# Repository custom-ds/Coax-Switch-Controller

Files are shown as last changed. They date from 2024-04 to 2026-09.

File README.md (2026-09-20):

# Coax Switch Controller

A WiFi-enabled coax antenna switch controller for amateur radio stations. It allows two radios to select one of six antennas each, with relay control driven by a custom PCB and an ESP32-based controller. The system supports both a front-panel interface and a built-in web UI / REST API.

## Overview

This project is designed to let a station operator:

- switch each radio between up to six antenna outputs
- optionally disconnect a radio from all antennas
- control the switch from the local front panel using a rotary knob and LCD
- control the switch from a browser or automation client over WiFi
- retain configuration and last-known antenna selections across reboots

The repository is divided into three main parts:

- [Firmware/](Firmware/) — ESP32 firmware for control logic, WiFi, API routes, and UI generation
- [Coax Switch Controller/](Coax%20Switch%20Controller/) — KiCad PCB design and fabrication outputs
- [3d Case/](3d%20Case/) — enclosure body, lid, and printable STL/BGCode exports

## Features

- Dual-radio antenna switching with six antenna positions per radio
- Shared collision protection so both radios cannot be assigned the same antenna simultaneously
- Persistent antenna state stored in ESP32 flash using Preferences
- Front-panel rotary knob and 16x2 LCD interface
- Built-in web interface served by the ESP32 itself
- REST-style API for external control and automation
- WiFi configuration with optional static IP support
- Custom relay-driver PCB design included in the repo

## Hardware

The firmware targets the SparkFun ESP32 Thing Plus C board. The controller also uses:

- SparkFun 16x2 SerLCD display
- SparkFun Qwiic Twist rotary knob
- custom relay driver PCB for switching the antenna control lines
- external 12V supply for the relay bank

The antenna switching model is based on two independent 3-bit select paths, one for each radio, with a shared latch/enable signal to prevent unstable switching during changes.

## Repository Layout

```text
.
├── Firmware/
│   ├── Firmware.ino
│   ├── config.h.template
│   ├── config.h
│   ├── README.md
│   └── LICENSE
├── Coax Switch Controller/
│   ├── Coax Switch Controller.kicad_pro
│   ├── Coax Switch Controller.kicad_sch
│   ├── Coax Switch Controller.kicad_pcb
│   ├── Bill of Materials.csv
│   └── Gerber/
├── 3d Case/
│   ├── Enclosure.FCStd
│   ├── Lid.FCStd
│   ├── .stl exports
│   └── related print files
├── README.md
├── test_config.html
├── test_interface.html
├── LICENSE
└── CLAUDE.md
```

## Firmware Build and Upload

The firmware is developed primarily in the Arduino IDE, although it can be edited in VS Code and uploaded from the Arduino IDE while both are pointed at the same .ino file.

### Required software

Install the following in the Arduino IDE:

1. ESP32 board package by Espressif Systems
2. Required libraries:
   - AsyncTCP
   - ESPAsyncTCP
   - ESPAsyncWebSrv
   - SparkFun Qwiic Twist Arduino Library
   - SparkFun SerLCD Arduino Library

### Important build flag for regex routes

The ESPAsyncWebSrv routes use regex matching for the API handlers. Without this flag, the web routes may silently fail to match.

For Arduino IDE, create or update the file:

- Windows: `%LOCALAPPDATA%\Arduino15\packages\espxxxx\hardware\espxxxx\{version}\platform.local.txt`
- Linux: `~/.arduino15/packages/espxxxx/hardware/espxxxx/{version}/platform.local.txt`

Add this line:

```text
compiler.cpp.extra_flags=-DASYNCWEBSERVER_REGEX=1
```

Then restart the Arduino IDE.

### Board selection and upload

1. Connect the ESP32 board over USB.
2. In Arduino IDE, choose the correct COM port.
3. Select the board: `SparkFun ESP32 Thing Plus C`.
4. Compile and upload the firmware.

> If the relay bank is already installed, the board may also require an external 12V input for the relay supply.

## Configuration

The firmware expects a local config file named `config.h` in [Firmware/](Firmware/). This file is intentionally gitignored and must be created from the template at [Firmware/config.h.template](Firmware/config.h.template).

The config file contains values for:

- WiFi SSID and password
- optional static IP configuration
- gateway, subnet, and DNS settings

Never commit the generated `config.h` file to version control.

## Web UI and API

The ESP32 serves a built-in web interface and REST-like endpoints for control and configuration. The firmware generates the HTML/CSS/JS dynamically rather than using a separate frontend project.

The repository also includes standalone browser preview files at the root:

- [test_interface.html](test_interface.html)
- [test_config.html](test_config.html)

These are useful for iterating on the interface layout without needing to flash the device each time.

## Front Panel Operation

The controller supports a front-panel workflow built around the rotary knob and LCD:

- normal mode allows selecting the active radio and changing the antenna
- the LCD shows current status and configuration information
- a long press enters configuration mode
- knob turns cycle through configuration screens
- a button click exits configuration mode and returns to the main operating view

## State Persistence

The controller stores persistent settings in the ESP32 `Preferences` namespace, including:

- last selected antenna per radio
- antenna names displayed in the UI
- LCD brightness and contrast settings
- knob RGB settings
- a long-lived API key

This ensures the device remembers its last configured state between power cycles.

## Project Notes

- There is no package manager or automated CI/test suite in this repo.
- Firmware development is hardware-focused and is flashed via the Arduino IDE.
- PCB and enclosure work is done in KiCad and FreeCAD, respectively.
- If the PCB or enclosure changes significantly, regenerate the output files manually so the exported fabrication artifacts remain consistent.

## More Information

For the most detailed firmware guidance, including required libraries, upload procedure, and environment setup, see [Firmware/README.md](Firmware/README.md).

For the PCB and enclosure sources, see:

- [Coax Switch Controller/](Coax%20Switch%20Controller/)
- [3d Case/](3d%20Case/)

## License

This project is distributed under the terms of the license included in [LICENSE](LICENSE).

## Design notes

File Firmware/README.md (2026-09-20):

# Coax Switch Controller - Firmware
The C firmware for the Sparkfun ESP32-based coax switch relay controller for amateur radio stations.

## Hardware
The W0ZC Coax Controller utilizes the "Sparkfun ESP32 Thing Plus C" as the main processor board and Wifi interface
for the coax switch controller. In addition, the Sparkfun 16x2 SerLCD module (Qwiic) and the Sparkfun Qwiic Twist
knob for interfacing.

A custom PCB is used to provide high side switching to the two sets of 6 coax relays.

## Programming the ESP32 

### Setting up the Environment
The ESP32 controller used in this project is the Sparkfun ESP32 Thing Plus C. To program it from the Arduino IDE 2.x 
platform, start by installing the board support tools.

In the Boards Manager section of Arduino IDE, search for the esp32 by Espressif Systems boards, and click the Install 
button.

**Important: install a 2.0.x release (2.0.17 is a good choice) of the esp32 board package, not 3.x.** The AsyncTCP/
ESPAsyncWebSrv libraries below are older forks that don't implement the lwIP TCPIP-core locking that Espressif's 3.x
board package (based on ESP-IDF v5.x) requires. Flashing this firmware with a 3.x board package installed will cause
the board to reboot in a loop with a crash like:

```
assert failed: tcp_alloc /IDF/components/lwip/lwip/src/core/tcp.c:1854 (Required to lock TCPIP core functionality!)
```

If you hit that, open Tools > Board > Boards Manager, install a 2.0.x version of "esp32 by Espressif Systems", select
it, restart the IDE, and re-upload.

There are some libraries that are required. Go to Tools and Manage Libraries. In the Search box, find and install these
libraries:

 * AsyncTCP (by dvarrel). Currently 1.1.4
 * ESPAsyncTCP (by dvarrel). Currently v1.2.4
 * ESPAsyncWebSrv (by dvarrel). Currently v1.2.7
 * Sparkfun Qwiic Twist Arduino Library (by Sparkfun Electronics). Currently v1.0.4
 * Sparkfun SerLCD Arduino Library (by Sparkfun Electronics). Currently v1.0.9

The ESPAsyncWebSrv utilizes Regular Expressions to handle some of the routing. This requires an additional file be
added to the Arduino IDE environment.

For arduino IDE: create/update platform.local.txt
 * Windows: C:\Users\(username)\AppData\Local\Arduino15\packages\espxxxx\hardware\espxxxx\{version}\platform.local.txt
 * Linux: ~/.arduino15/packages/espxxxx/hardware/espxxxx/{version}/platform.local.txt

Unless there are other items that have previously been added, the platform.local.txt file should just contain
a single line:

```
compiler.cpp.extra_flags=-DASYNCWEBSERVER_REGEX=1
```

### Programming the Firmware
Plug in the USB-C cable from the PC to the Sparkfun controller board. If the coax relays are already attached to the
Switch Controller, you may need to apply external 12V to the Controller.

Click the Select Board dropdown, and select the COM port that is associated with the Sparkfun device.

That will bring up another window where you can select the type of board being programmed. Scroll down or search the list
for "Sparkfun ESP32 Thing Plus C" and click the OK button.

In the upper left corner on the IDE, click the Right-Arrow (Upload) button to begin the compile and upload of the firmware.

### Using Visual Studio Code
I find it more efficient to code within Microsoft's Visual Studio Code, rather than directly in the Arduino IDE. To do that,
open up the .ino file inside of VSCode and make any code changes in there.

Leave the Arduino IDE open in the background, with the same .ino firmware file open. 

Modify the code inside of VSCode and save the changes. Alt-Tab into the Arduino IDE and just click the Upload button to 
load the firmware on the ESP32. If you need to make a small tweak inside of the Arduino IDE, go ahead and save, and VSCode
will immediately reflect the changes when to switch task back to it.

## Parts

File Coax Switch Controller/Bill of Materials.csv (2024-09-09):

Reference | Value | Datasheet | Footprint | Qty | DNP | DigiKey-PN | SparkFun-PN
C1,C3,C6 | 10uF | ~ | Capacitor_SMD:CP_Elec_4x5.3 | 3 |  | PCE3795CT-ND
C2,C4,C5,C7,C8,C9 | .01uF | ~ | Capacitor_SMD:C_0805_2012Metric_Pad1.18x1.45mm_HandSolder | 6 |  | C0603C103J5REC7411
D1,D2,D3,D4,D5,D6,D7,D8,D9,D10,D11,D12,D25 | 1N4007 | -- mixed values -- | Diode_SMD:D_SOD-123F | 13 |  | 1655-1N4007FLCT-ND
D13,D14,D15,D16,D17,D18,D19,D20,D21,D22,D23,D24 | LED | ~ | Diode_SMD:D_0805_2012Metric_Pad1.15x1.40mm_HandSolder | 12 |  | 732-4985-1-ND
FB1,FB2,FB3,FB4,FB5,FB6,FB7,FB8,FB9,FB10,FB11,FB12,FB13,FB14,FB15,FB16 | FerriteBead | ~ | Inductor_SMD:L_0805_2012Metric_Pad1.05x1.20mm_HandSolder | 16 |  | 240-2411-1-ND
H1,H2,H3,H4 | MountingHole | ~ | MountingHole:MountingHole_3.2mm_M3 | 4
J1,J2 | 8P8C | ~ | Connector_RJ:RJ45_Amphenol_54602-x08_Horizontal | 2 |  | 609-1046-ND
J3 | Screw_Terminal_01x02 | ~ | TerminalBlock_RND:TerminalBlock_RND_205-00001_1x02_P5.00mm_Horizontal | 1 |  | 732-10955-ND
Q1,Q2,Q3,Q4,Q5,Q6,Q7,Q8,Q9,Q10,Q11,Q12 | MMBT3904 | https://www.onsemi.com/pdf/datasheet/pzt3904-d.pdf | Package_TO_SOT_SMD:SOT-23 | 12 |  | MMBT3904TPMSCT-ND
Q13,Q14,Q15,Q16,Q17,Q18,Q19,Q20,Q21,Q22,Q23,Q24 | DMP2004K-7 |  | Package_TO_SOT_SMD:SOT-23 | 12 |  | DMP2004KDICT-ND
R1,R2,R3,R4,R5,R6,R7,R8,R9,R10,R11,R12 | 4.7k | ~ | Resistor_SMD:R_0805_2012Metric_Pad1.20x1.40mm_HandSolder | 12 |  | 311-4.70KCRCT-ND
R13,R14,R15,R16,R17,R18,R19,R20,R21,R22,R23,R24 | 100k | ~ | Resistor_SMD:R_0805_2012Metric_Pad1.20x1.40mm_HandSolder | 12 |  | 311-100KARCT-ND
R25,R26,R27,R28,R29,R30,R31,R32,R33,R34,R35,R36 | 10k | ~ | Resistor_SMD:R_0805_2012Metric_Pad1.20x1.40mm_HandSolder | 12 |  | 311-10.0KCRCT-ND
R37,R38,R39,R40,R41,R42,R43,R44,R45,R46,R47,R48 | 1k | ~ | Resistor_SMD:R_0805_2012Metric_Pad1.20x1.40mm_HandSolder | 12 |  | 311-1.00KCRCT-ND
U1 | ~ |  | Custom DS:ESP32-WROOM Thing Plus C | 1 |  |  | SPX-18018
U2,U3 | 74HC238 | http://www.ti.com/lit/ds/symlink/cd74hc238.pdf | Package_SO:SOIC-16_3.9x9.9mm_P1.27mm | 2 |  | 296-9188-5-ND
U4 | LM1085-5.0 | http://www.ti.com/lit/ds/symlink/lm1085.pdf | Package_TO_SOT_SMD:TO-263-3_TabPin2 | 1 |  | LM1086ISX-5.0/NOPBCT-ND

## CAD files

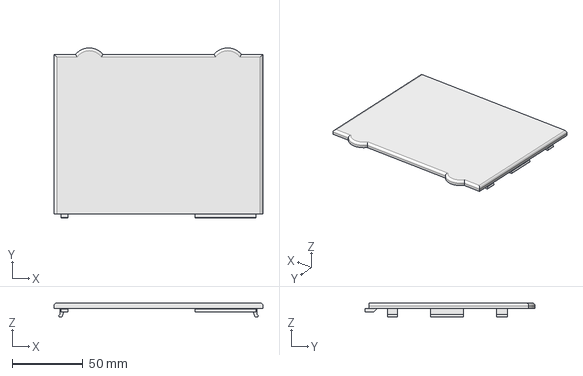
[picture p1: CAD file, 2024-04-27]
3d Case/Lid.FCStd
148.0 x 120.5 x 10.0 mm

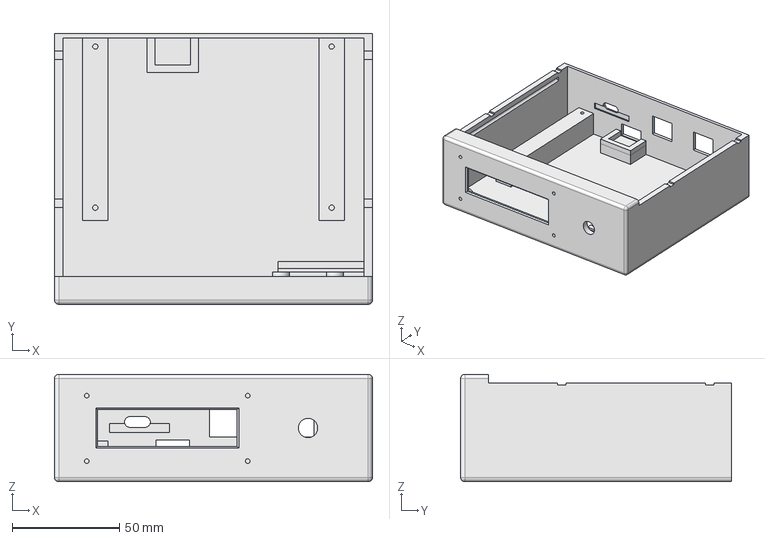
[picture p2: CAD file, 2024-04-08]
3d Case/Enclosure.FCStd
148.0 x 126.0 x 50.0 mm

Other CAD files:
3d Case/Enclosure-Body.stl
3d Case/Lid.stl

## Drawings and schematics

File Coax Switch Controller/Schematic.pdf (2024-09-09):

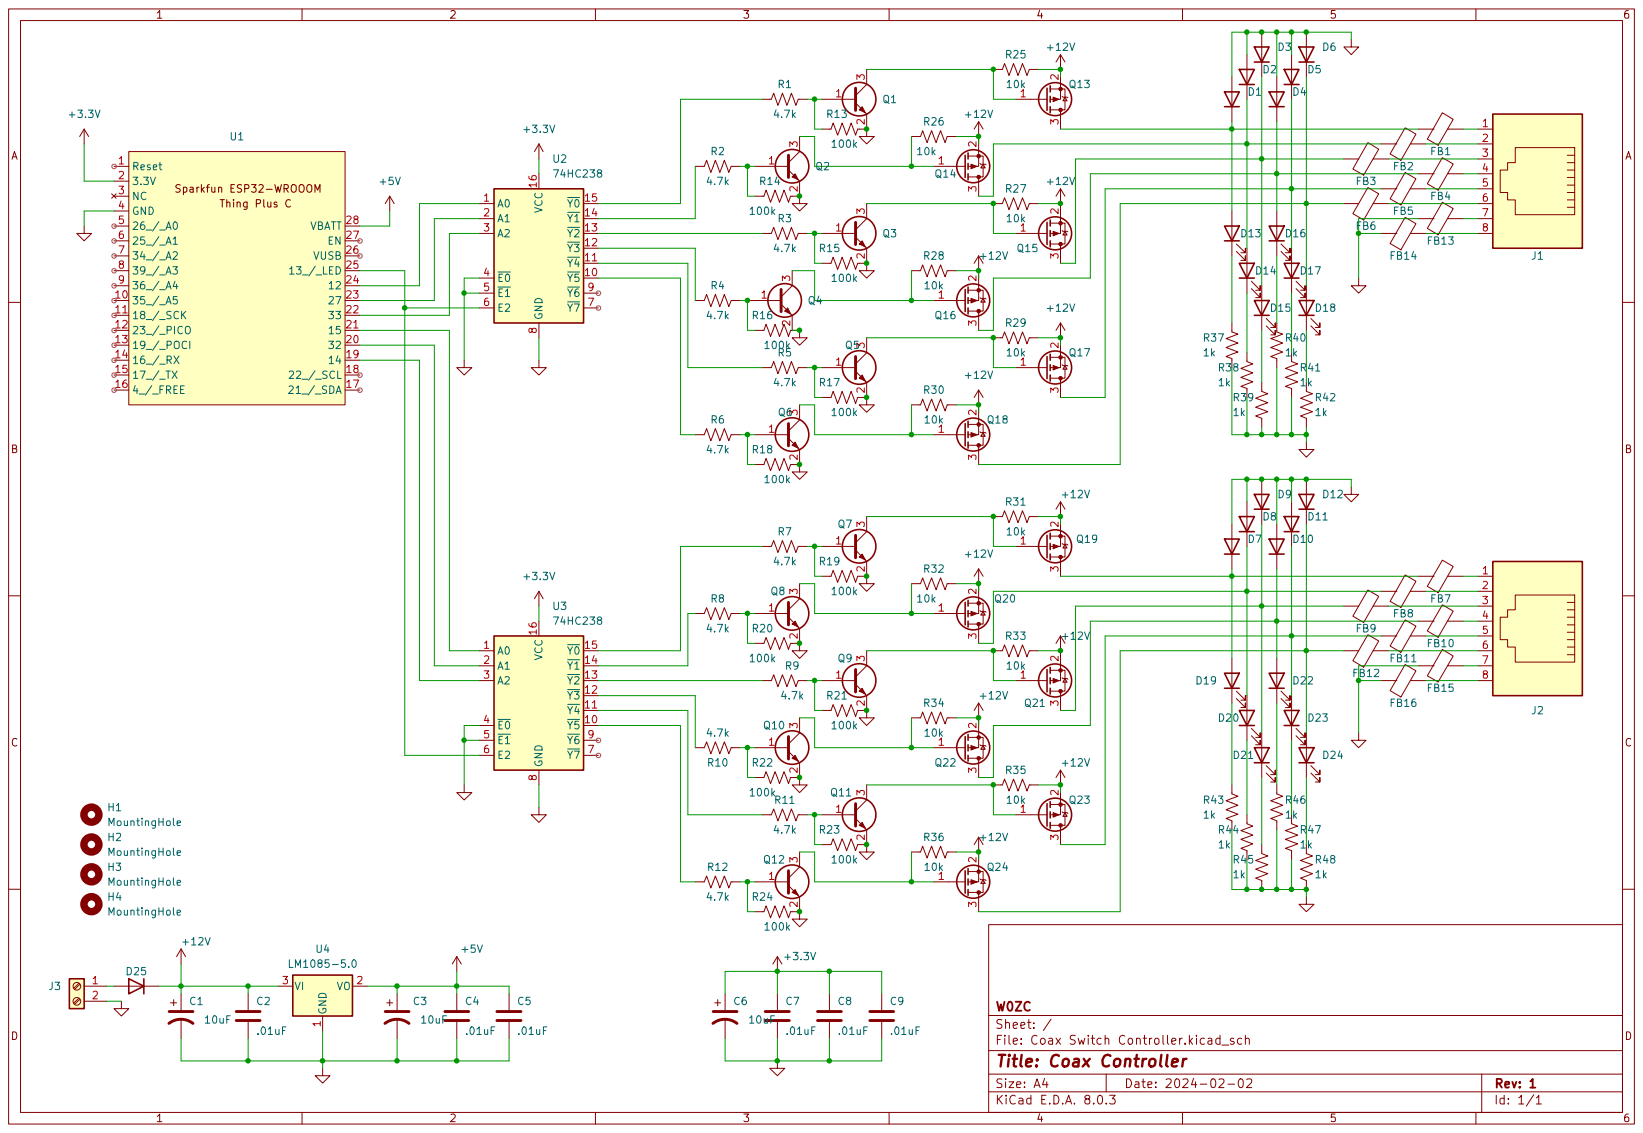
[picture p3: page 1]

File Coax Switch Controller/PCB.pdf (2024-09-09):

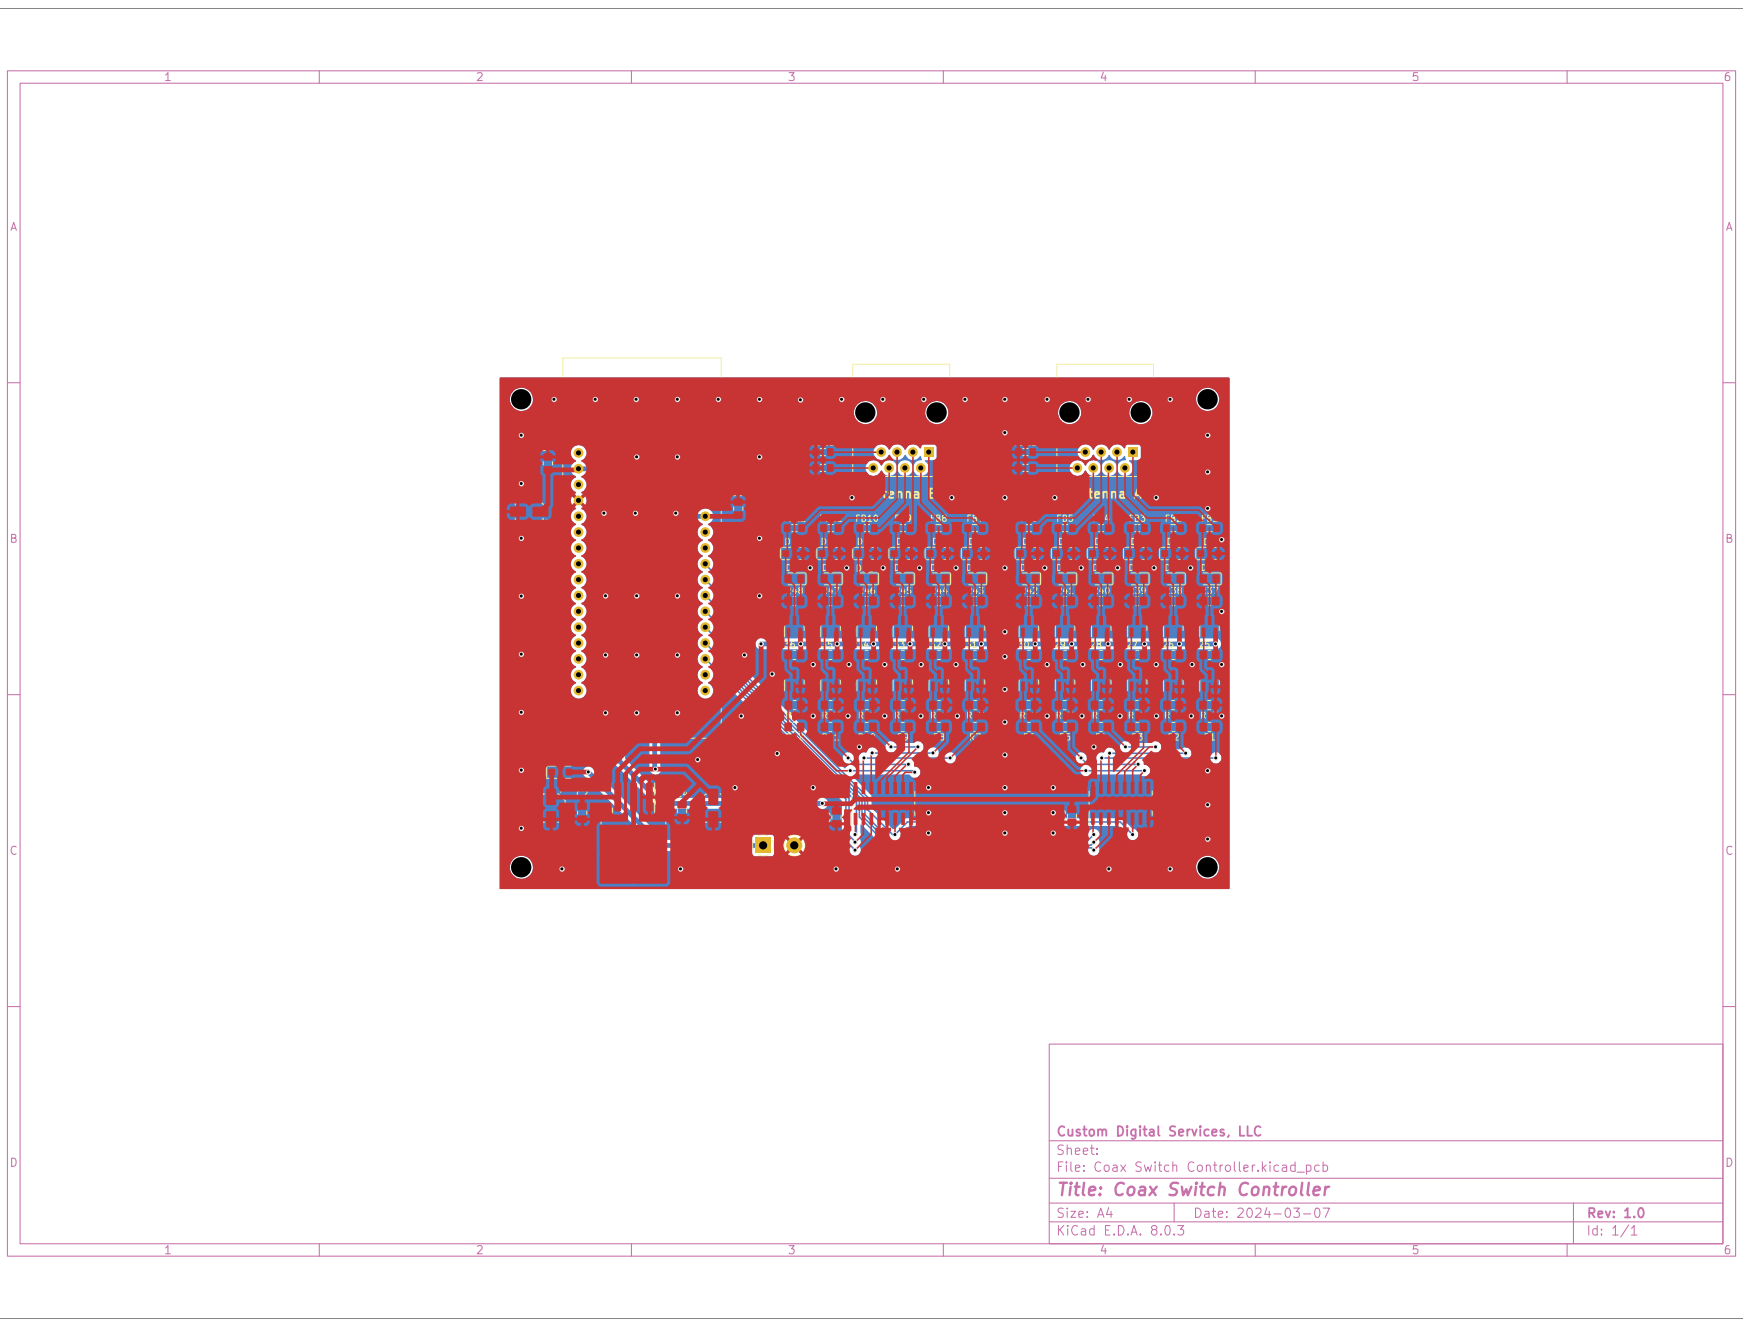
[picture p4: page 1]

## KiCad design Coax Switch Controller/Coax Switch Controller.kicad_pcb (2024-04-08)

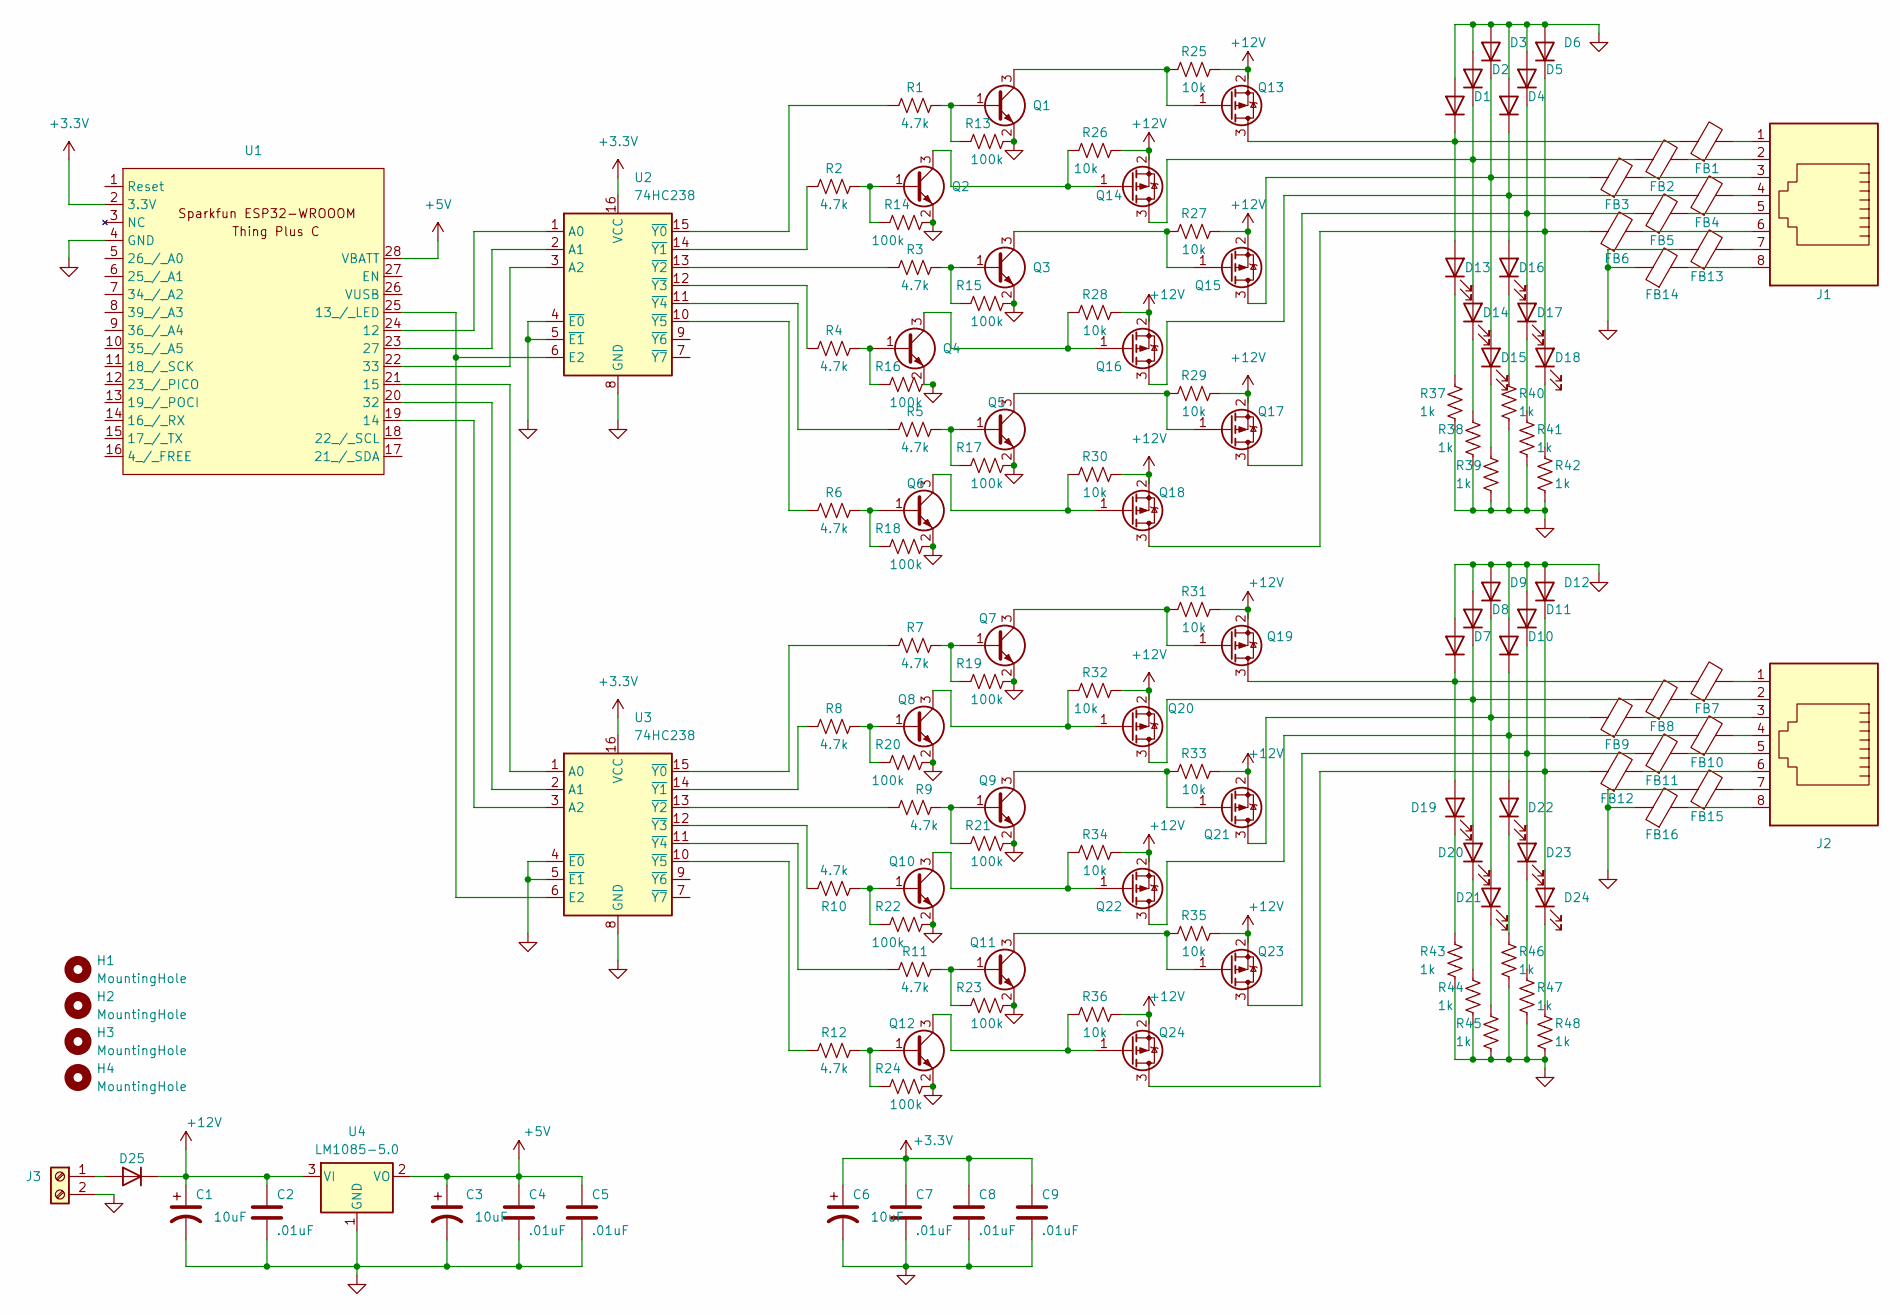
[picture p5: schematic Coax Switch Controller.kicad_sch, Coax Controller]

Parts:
C1, C3, C6: 10uF; CP_Elec_4x5.3
C2, C4, C5, C7, C8, C9: .01uF; C_0805_2012Metric_Pad1.18x1.45mm_HandSolder
D1, D2, D3, D4, D5, D6, D7, D8, D9, D10, D11, D12: MRA4007T3G; D_SOD-123F
D13, D14, D15, D16, D17, D18, D19, D20, D21, D22, D23, D24: LED; D_0805_2012Metric_Pad1.15x1.40mm_HandSolder
D25: 1N4007; D_SOD-123F
FB1, FB2, FB3, FB4, FB5, FB6, FB7, FB8, FB9, FB10, FB11, FB12, FB13, FB14, FB15, FB16: FerriteBead; L_0805_2012Metric_Pad1.05x1.20mm_HandSolder
H1, H2, H3, H4: MountingHole; MountingHole_3.2mm_M3
J1, J2: 8P8C; RJ45_Amphenol_54602-x08_Horizontal
J3: Screw_Terminal_01x02; TerminalBlock_RND_205-00001_1x02_P5.00mm_Horizontal
Q1, Q2, Q3, Q4, Q5, Q6, Q7, Q8, Q9, Q10, Q11, Q12: MMBT3904; SOT-23
Q13, Q14, Q15, Q16, Q17, Q18, Q19, Q20, Q21, Q22, Q23, Q24: DMP2004K-7; SOT-23
R1, R2, R3, R4, R5, R6, R7, R8, R9, R10, R11, R12: 4.7k; R_0805_2012Metric_Pad1.20x1.40mm_HandSolder
R13, R14, R15, R16, R17, R18, R19, R20, R21, R22, R23, R24: 100k; R_0805_2012Metric_Pad1.20x1.40mm_HandSolder
R25, R26, R27, R28, R29, R30, R31, R32, R33, R34, R35, R36: 10k; R_0805_2012Metric_Pad1.20x1.40mm_HandSolder
R37, R38, R39, R40, R41, R42, R43, R44, R45, R46, R47, R48: 1k; R_0805_2012Metric_Pad1.20x1.40mm_HandSolder
U1: ESP32-WROOM Thing Plus C
U2, U3: 74HC238; SOIC-16_3.9x9.9mm_P1.27mm
U4: LM1085-5.0; TO-263-3_TabPin2

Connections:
+3.3V: C6.1, C7.1, C8.1, C9.1, U1.2 (3.3V), U2.16 (VCC), U3.16 (VCC)
+5V: C3.1, C4.1, C5.1, U1.28 (VBATT), U4.2 (VO)
+12V: C1.1, C2.1, D25.1 (K), Q13.2 (S), Q14.2 (S), Q15.2 (S), Q16.2 (S), Q17.2 (S), Q18.2 (S), Q19.2 (S), Q20.2 (S), Q21.2 (S), Q22.2 (S), Q23.2 (S), Q24.2 (S), R25.2, R26.2, R27.2, R28.2, R29.2, R30.2, R31.2, R32.2, R33.2, R34.2, R35.2, R36.2, U4.3 (VI)
GND: C1.2, C2.2, C3.2, C4.2, C5.2, C6.2, C7.2, C8.2, C9.2, D1.2 (A), D2.2 (A), D3.2 (A), D4.2 (A), D5.2 (A), D6.2 (A), D7.2 (A), D8.2 (A), D9.2 (A), D10.2 (A), D11.2 (A), D12.2 (A), FB13.1, FB14.1, FB15.1, FB16.1, J3.2, Q1.2 (E), Q2.2 (E), Q3.2 (E), Q4.2 (E), Q5.2 (E), Q6.2 (E), Q7.2 (E), Q8.2 (E), Q9.2 (E), Q10.2 (E), Q11.2 (E), Q12.2 (E), R13.1, R14.1, R15.1, R16.1, R17.1, R18.1, R19.1, R20.1, R21.1, R22.1, R23.1, R24.1, R37.1, R38.1, R39.1, R40.1, R41.1, R42.1, R43.1, R44.1, R45.1, R46.1, R47.1, R48.1, U1.4 (GND), U2.4 (~E0), U2.5 (~E1), U2.8 (GND), U3.4 (~E0), U3.5 (~E1), U3.8 (GND), U4.1 (GND)
unnamed: D1.1 (K), D13.2 (A), FB1.1, Q13.3 (D)
unnamed: D10.1 (K), D22.2 (A), FB10.1, Q22.3 (D)
unnamed: D11.1 (K), D23.2 (A), FB11.1, Q23.3 (D)
unnamed: D12.1 (K), D24.2 (A), FB12.1, Q24.3 (D)
unnamed: D13.1 (K), R37.2
unnamed: D2.1 (K), D14.2 (A), FB2.1, Q14.3 (D)
unnamed: D14.1 (K), R38.2
unnamed: D3.1 (K), D15.2 (A), FB3.1, Q15.3 (D)
unnamed: D15.1 (K), R39.2
unnamed: D4.1 (K), D16.2 (A), FB4.1, Q16.3 (D)
unnamed: D16.1 (K), R40.2
unnamed: D5.1 (K), D17.2 (A), FB5.1, Q17.3 (D)
unnamed: D17.1 (K), R41.2
unnamed: D6.1 (K), D18.2 (A), FB6.1, Q18.3 (D)
unnamed: D18.1 (K), R42.2
unnamed: D7.1 (K), D19.2 (A), FB7.1, Q19.3 (D)
unnamed: D19.1 (K), R43.2
unnamed: D8.1 (K), D20.2 (A), FB8.1, Q20.3 (D)
unnamed: D20.1 (K), R44.2
unnamed: D9.1 (K), D21.2 (A), FB9.1, Q21.3 (D)
unnamed: D21.1 (K), R45.2
unnamed: D22.1 (K), R46.2
unnamed: D23.1 (K), R47.2
unnamed: D24.1 (K), R48.2
unnamed: D25.2 (A), J3.1
unnamed: FB1.2, J1.1
unnamed: FB2.2, J1.2
unnamed: FB3.2, J1.3
unnamed: FB4.2, J1.4
unnamed: FB5.2, J1.5
unnamed: FB6.2, J1.6
unnamed: FB7.2, J2.1
unnamed: FB8.2, J2.2
unnamed: FB9.2, J2.3
unnamed: FB10.2, J2.4
unnamed: FB11.2, J2.5
unnamed: FB12.2, J2.6
unnamed: FB13.2, J1.7
unnamed: FB14.2, J1.8
unnamed: FB15.2, J2.7
unnamed: FB16.2, J2.8
unnamed: Q1.1 (B), R1.2, R13.2
unnamed: Q1.3 (C), Q13.1 (G), R25.1
unnamed: Q2.1 (B), R2.2, R14.2
unnamed: Q3.1 (B), R3.2, R15.2
unnamed: Q4.1 (B), R4.2, R16.2
unnamed: Q5.1 (B), R5.2, R17.2
unnamed: Q6.1 (B), R6.2, R18.2
unnamed: Q7.1 (B), R7.2, R19.2
unnamed: Q8.1 (B), R8.2, R20.2
unnamed: Q9.1 (B), R9.2, R21.2
unnamed: Q10.1 (B), R10.2, R22.2
unnamed: Q10.3 (C), Q22.1 (G), R34.1
unnamed: Q11.1 (B), R11.2, R23.2
unnamed: Q11.3 (C), Q23.1 (G), R35.1
unnamed: Q12.1 (B), R12.2, R24.2
unnamed: Q12.3 (C), Q24.1 (G), R36.1
unnamed: Q2.3 (C), Q14.1 (G), R26.1
unnamed: Q3.3 (C), Q15.1 (G), R27.1
unnamed: Q4.3 (C), Q16.1 (G), R28.1
unnamed: Q5.3 (C), Q17.1 (G), R29.1
unnamed: Q6.3 (C), Q18.1 (G), R30.1
unnamed: Q7.3 (C), Q19.1 (G), R31.1
unnamed: Q8.3 (C), Q20.1 (G), R32.1
unnamed: Q9.3 (C), Q21.1 (G), R33.1
unnamed: U1.24 (12), U2.1 (A0)
unnamed: U1.25 (13_/_LED), U2.6 (E2), U3.6 (E2)
unnamed: U1.19 (14), U3.3 (A2)
unnamed: U1.21 (15), U3.1 (A0)
unnamed: U1.23 (27), U2.2 (A1)
unnamed: U1.20 (32), U3.2 (A1)
unnamed: U1.22 (33), U2.3 (A2)
unnamed: R1.1, U2.15 (~Y0)
unnamed: R2.1, U2.14 (~Y1)
unnamed: R3.1, U2.13 (~Y2)
unnamed: R4.1, U2.12 (~Y3)
unnamed: R5.1, U2.11 (~Y4)
unnamed: R6.1, U2.10 (~Y5)
unnamed: R7.1, U3.15 (~Y0)
unnamed: R8.1, U3.14 (~Y1)
unnamed: R9.1, U3.13 (~Y2)
unnamed: R10.1, U3.12 (~Y3)
unnamed: R11.1, U3.11 (~Y4)
unnamed: R12.1, U3.10 (~Y5)

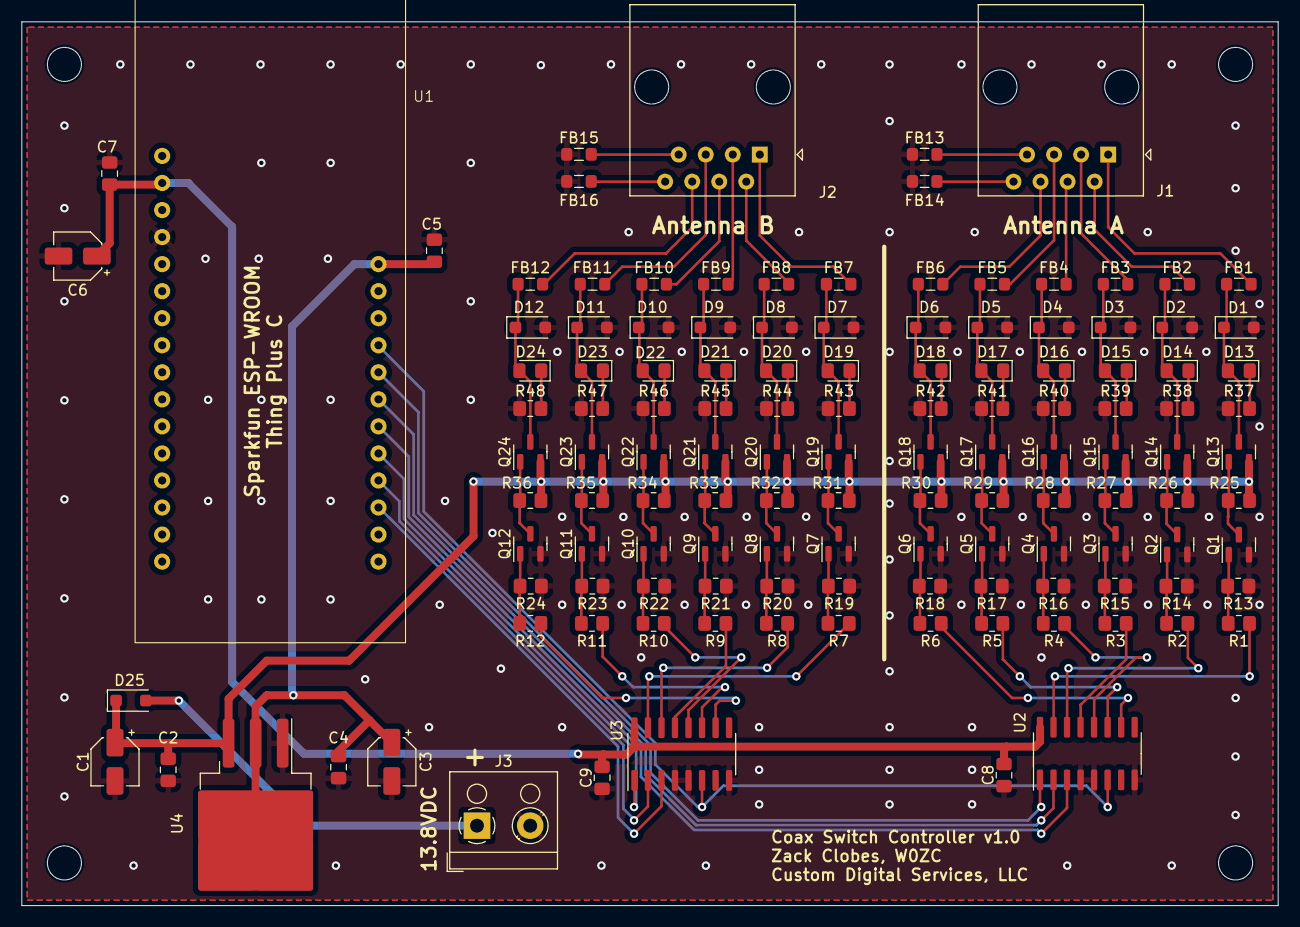
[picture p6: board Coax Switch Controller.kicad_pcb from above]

Board: 2 copper layers, 118.0 x 83.0 mm, 133 parts (0 on the bottom side), 88 nets.

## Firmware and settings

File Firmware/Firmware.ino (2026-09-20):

/* Coax Switch uses: Sparkfun ESP32 Thing Plus C */

// CAUTION: If the board reboots in a constant loop after flashing, see the README - it's very likely an
// esp32 board package version mismatch (needs 2.0.x), not a bug in this sketch.

// Add buildflag ASYNCWEBSERVER_REGEX to enable the regex support

// For platformio: platformio.ini:
//  build_flags = 
//      -DASYNCWEBSERVER_REGEX

// For arduino IDE: create/update platform.local.txt
// Windows: C:\Users\(username)\AppData\Local\Arduino15\packages\espxxxx\hardware\espxxxx\{version}\platform.local.txt
// Linux: ~/.arduino15/packages/espxxxx/hardware/espxxxx/{version}/platform.local.txt
//
// compiler.cpp.extra_flags=-DASYNCWEBSERVER_REGEX=1
//
// Restart the IDE after making changes to the platform.local.txt file


#include "config.h"


#include <WiFi.h>
#include <AsyncTCP.h>
#include <ESPAsyncWebSrv.h>

#include <WiFiClient.h>
#include <Wire.h>
#include <SparkFun_Qwiic_Twist_Arduino_Library.h>
#include <SerLCD.h>

#include <Preferences.h>

#include "esp_system.h"
#include "freertos/FreeRTOS.h"
#include "freertos/semphr.h"


/*
 * Wifi credentials are stored in config.h file. See the template.
 *
const char* ssid = "";
const char* password = "";
*/

//Defines
#define FIRMWARE_VERSION "1.1.0"
#define PAGE_TITLE "W0ZC Coax Controller"

#define DISPLAY_ADDRESS1 0x72 //This is the default address of the OpenLCD
#define MAX_CONFIG_SCREENS 6

//Global Variables
SerLCD lcd; // Initialize the library with default I2C address 0x72
TWIST twist;


Preferences prefs;
AsyncWebServer server(80);

// Guards all access to the I2C bus (lcd + twist). loop() and the AsyncWebServer route
// handlers run in different tasks and both touch Wire/lcd/twist; without this mutex they
// can collide mid-transaction and wedge the I2C bus, which under heavy network load
// (more frequent async callback scheduling) shows up as a hang -> watchdog reset.
SemaphoreHandle_t i2cMutex;

int radio1 = 0;   //default both to disconnected
int radio2 = 0;   //default both to disconnected
int radioSelected = 1;

int displayMode = 1;    //1 = normal operation, 2 = configuration mode
int configScreen = 0;     //The current configuration screen being displayed

String sessionAPIKey = "";

// Define the labels for the 6 antennas + Disconnect
String coaxDescriptions[] = {"Disconnect", "Antenna 1", "Antenna 2", "Antenna 3", "Antenna 4", "Antenna 5", "Antenna 6"};



//Function Prototypes
void updateLCD();
void showSplash();
void updateConfigScreen(int diff);
void updateAntenna(int radio, int diff);
void connectAntenna(int radio, int antenna, bool incrOnCollision);
String getAPIKey(bool force);
void configureLCD(int r, int g, int b, int contrast);
void configureTwist(int r, int g, int b);
String generateKey();
int getRandom(int max);
bool checkAPIKey(String key);
void saveAntennaName(int antenna, String name);
void factoryReset();
void loadAntennas();
void displayConfiguration();

void printResetReason();

void notFound(AsyncWebServerRequest *request);
String getHeader();
String getFooter(String javascript);
String getPageInterface();
String getPageConfiguration();
String getJavascript();
String getCSS();






/******************************************************************************************/
void setup(void) {
  Serial.begin(115200);

  //Log why the last reset happened. If the device is rebooting unexpectedly, this tells us
  //whether it's a watchdog, brownout, panic, etc. instead of having to guess.
  printResetReason();

  i2cMutex = xSemaphoreCreateMutex();

  //Configure the digital I/O pins
  pinMode(13, OUTPUT);
  digitalWrite(13, LOW);    //Disable the demultiplexer until we're fully configured

  //Multiplexer 1
  pinMode(12, OUTPUT);
  pinMode(27, OUTPUT);
  pinMode(33, OUTPUT);

  //Multiplexer 2
  pinMode(15, OUTPUT);
  pinMode(32, OUTPUT);
  pinMode(14, OUTPUT);



  prefs.begin("coax");
  radio1 = prefs.getInt("radio1");
  radio2 = prefs.getInt("radio2");

  //Do some sanity checking on the antennas selected
  if (radio1 < 0 || radio2 < 0) {
    radio1 = 0;
    radio2 = 0;
  }
  if (radio1 > 6 || radio2 > 6) {
    radio1 = 0;
    radio2 = 0;
  }
  if (radio1 == radio2 && radio1 > 0) {
    radio1 = 0;
    radio2 = 0;
  }


  //Send the reset command to the display - this forces the cursor to return to the beginning of the display
  Wire.begin();
  lcd.begin(Wire); //Set up the LCD for I2C communication
  showSplash();

  Serial.println("Starting Wifi");
  WiFi.mode(WIFI_STA);

  // Configures static IP address
  //see if we're configured for static IP
  if (useStaticIP) {
    Serial.println("Using static IP");
    if (!WiFi.config(local_IP, gateway, subnet, primaryDNS, secondaryDNS)) {
      Serial.println("...STA Failed to configure static IP");
    }
  } else {
    Serial.println("Using DHCP");
  }



  WiFi.begin(ssid, password);
  Serial.println("");




  // Wait for connection
  while (WiFi.status() != WL_CONNECTED) {
    delay(500);
    Serial.print(".");
  }

  //Disable WiFi modem sleep. Power-save timing tends to interact badly with AsyncTCP when the
  //channel is busy (e.g. heavy traffic from other devices on the same network), which is a
  //common cause of ESP32 hangs/resets under network load even when traffic isn't addressed
  //to this device.
  WiFi.setSleep(false);


  //Load the antenna names from eeprom
  loadAntennas();

  //default the relays to whatever is currently set (from eeprom)
  connectAntenna(1, radio1, true);
  connectAntenna(2, radio2, true);
  

  if (twist.begin() == false) {
    Serial.println("Twist is not connected.");

  }


  // ******* Server Route Handlers *******
  // Server Route Handler: /api/{key}/connect/{radio}/{antenna}
  server.on("^\\/api\\/([A-Z0-9]+)\\/connect\\/([0-9])\\/([0-9])$", HTTP_POST, [] (AsyncWebServerRequest *request) {
    String apiKey = request->pathArg(0);
    String radio = request->pathArg(1);
    String antenna = request->pathArg(2);
    int radioID = radio.toInt();
    int antennaID = antenna.toInt();

    if (checkAPIKey(apiKey) && radioID >= 1 && radioID <= 2 && antennaID >=0 && antennaID <=6) {

      //connectAntenna() touches the I2C-driven LCD; take the same lock loop() uses so this
      //can't interleave with a knob-driven display update on the other task.
      xSemaphoreTake(i2cMutex, portMAX_DELAY);
      connectAntenna(radioID, antennaID, true);
      xSemaphoreGive(i2cMutex);
      request->send(200, "text/plain", "Radio " + radio + " connected to antenna " + antenna);
    } else {
      request->send(400, "text/plain", "API Request Denied. Valid key?");
    }
  });

  // Server Route Handler: /api/{key}/set/knob/rgb/{r}/{g}/{b}
  server.on("^\\/api\\/([A-Z0-9]+)\\/set\\/knob\\/rgb\\/([0-9]+)\\/([0-9]+)\\/([0-9]+)$", HTTP_POST, [] (AsyncWebServerRequest *request) {
    String apiKey = request->pathArg(0);
    String tmp = request->pathArg(1);
    int r = tmp.toInt();
    tmp = request->pathArg(2);
    int g = tmp.toInt();
    tmp = request->pathArg(3);
    int b = tmp.toInt();

    //Check the API key
    if (!checkAPIKey(apiKey)) {
      request->send(400, "text/plain", "API Request Denied. Valid key?");
      return;
    } 

    if (r >= 0 && r <= 255 && g >= 0 && g <= 255 && b >= 0 && b <= 255) {
      xSemaphoreTake(i2cMutex, portMAX_DELAY);
      configureTwist(r, g, b);
      xSemaphoreGive(i2cMutex);
      request->send(200, "text/plain", "Twist Knob configured");
    } else {
      request->send(400, "text/plain", "Invalid RGB values");
    }

  });

  // Server Route Handler: /api/{key}/set/lcd/rgb/{r}/{g}/{b}/{contrast}
  server.on("^\\/api\\/([A-Z0-9]+)\\/set\\/lcd\\/rgb\\/([0-9]+)\\/([0-9]+)\\/([0-9]+)\\/([0-9]+)$", HTTP_POST, [] (AsyncWebServerRequest *request) {
    String apiKey = request->pathArg(0);
    String tmp = request->pathArg(1);
    int r = tmp.toInt();
    tmp = request->pathArg(2);
    int g = tmp.toInt();
    tmp = request->pathArg(3);
    int b = tmp.toInt();
    tmp = request->pathArg(4);
    int contrast = tmp.toInt();

    //Check the API key
    if (!checkAPIKey(apiKey)) {
      request->send(400, "text/plain", "API Request Denied. Valid key?");
      return;
    } 

    if (r >= 0 && r <= 255 && g >= 0 && g <= 255 && b >= 0 && b <= 255 && contrast >= 0 && contrast <= 255) {
      xSemaphoreTake(i2cMutex, portMAX_DELAY);
      configureLCD(r, g, b, contrast);
      updateLCD();    //return to whatever screen we were on.
      xSemaphoreGive(i2cMutex);
      request->send(200, "text/plain", "LCD configured");
    } else {
      request->send(400, "text/plain", "Invalid RGB values");
    }

  });


  // Server Route Handler: /api/{key}/set/antenna/{antenna}/{name}
  server.on("^\\/api\\/([A-Z0-9]+)\\/set\\/antenna\\/([0-9]+)\\/(.+)$", HTTP_POST, [] (AsyncWebServerRequest *request) {
    String apiKey = request->pathArg(0);
    String antenna = request->pathArg(1);
    String name = request->pathArg(2);

    int antennaID = antenna.toInt();

    //Check the API key
    if (!checkAPIKey(apiKey)) {
      request->send(400, "text/plain", "API Request Denied. Valid key?");
      return;
    }

    //limit the antenna name to 13 characters
    if (name.length() > 13) {
      name = name.substring(0, 13);
    }

    if (antennaID >= 0 && antennaID <= 6) {
      saveAntennaName(antennaID, name);
      loadAntennas();   //populate the array of antenna names
      xSemaphoreTake(i2cMutex, portMAX_DELAY);
      updateLCD();    //update the LCD display with the new name
      xSemaphoreGive(i2cMutex);
      request->send(200, "text/plain", "Antenna " + antenna + " name saved");
    } else {
      request->send(400, "text/plain", "Invalid antenna number");
    }

  });

  // Server Route Handler: /api/{key}/get/antenna/{antenna}
  server.on("^\\/api\\/([A-Z0-9]+)\\/get\\/antenna\\/([0-9]+)$", HTTP_GET, [] (AsyncWebServerRequest *request) {
    String apiKey = request->pathArg(0);
    String antenna = request->pathArg(1);

    int antennaID = antenna.toInt();

    //Check the API key
    if (!checkAPIKey(apiKey)) {
      request->send(400, "text/plain", "API Request Denied. Valid key?");
      return;
    }

    if (antennaID >= 0 && antennaID <= 6) {
      request->send(200, "text/plain", coaxDescriptions[antennaID]);
    } else {
      request->send(400, "text/plain", "Invalid antenna number");
    }

  });

  // Server Route Handler: /api/{key}/get/radio/{radioID}
  server.on("^\\/api\\/([A-Z0-9]+)\\/get\\/radio\\/([0-9])$", HTTP_GET, [] (AsyncWebServerRequest *request) {
    String apiKey = request->pathArg(0);
    String radio = request->pathArg(1);

    int radioID = radio.toInt();

    //Check the API key
    if (!checkAPIKey(apiKey)) {
      request->send(400, "text/plain", "API Request Denied. Valid key?");
      return;
    }

    if (radioID == 1) {
      request->send(200, "text/plain", String(radio1));
    } else if (radioID == 2) {
      request->send(200, "text/plain", String(radio2));
    } else if (radioID == 0) {
      //return both radios separated by a :
      request->send(200, "text/plain", String(radio1) + ":" + String(radio2));
    } else {
      request->send(400, "text/plain", "Invalid radio number");
    }

  });

  // Server Route Handler: /
  server.on("/", HTTP_GET, [](AsyncWebServerRequest *request) {
    request->send(200, "text/html", getPageInterface());
  });

  // Server Route Handler: /config
  server.on("/config", HTTP_GET, [](AsyncWebServerRequest *request) {
    request->send(200, "text/html", getPageConfiguration());
  });

  // Server Route Handler: /main.js
  server.on("/main.js", HTTP_GET, [](AsyncWebServerRequest *request) {
    request->send(200, "text/javascript", getJavascript());
  });

  // Server Route Handler: /main.css
  server.on("/main.css", HTTP_GET, [](AsyncWebServerRequest *request) {
    request->send(200, "text/css", getCSS());
  });
  

  // Server Route Handler: Not Found
  server.onNotFound(notFound);



  server.begin();

 //Generate the temporary session API key - Note that this should happen after Wifi has been established.
  sessionAPIKey = generateKey();  

  //Get the API key. Generate a new one if necessary
  String apiKey = getAPIKey(false);   //Don't force the creation of a new key if one already exists

  //Show the running configuration on the Serial port
  displayConfiguration();
}
/******************************************************************************************/
void loop(void) {

  int diff;
  static int pressCount = 0;

  //Hold the I2C bus for the whole knob-read + display-update cycle so an AsyncWebServer
  //route handler can't interleave a Wire transaction with this one (see i2cMutex comment above).
  xSemaphoreTake(i2cMutex, portMAX_DELAY);

  if (twist.isPressed()) {
    pressCount++;
  }

  if (twist.isClicked()) {
    //the button was clicked

    if (pressCount < 5) {
      //short press - toggle the selected radio

      if (displayMode == 1) {
        //we're showing the connected antennas - normal operation mode
        if (radioSelected == 1) radioSelected = 2;
        else radioSelected = 1;
      } else {
        //we were in configuration mode - toggle the display mode
        displayMode = 1;
      }
    } else {
      //Long press - go into configuration mode
      displayMode = 2;
      configScreen = 0;   //start at the first configuration screen
    }


    pressCount = 0;     //reset the counter since we've released the button.
    updateLCD();



  }
  diff = twist.getDiff();
  if (diff != 0) {
    if (displayMode == 1) {
      //we're in the normal operation mode - just update the selected antenna
      updateAntenna(radioSelected, diff);
    } else {
      //we're in configuration mode - update the configuration screen
      updateConfigScreen(diff);
    }


  }

  xSemaphoreGive(i2cMutex);

  delay(100);
}









/******************************************************************************************
                    Functions
******************************************************************************************/
void updateLCD() {
/* 
Shows the currently selected antennas that are connected to the radios. If we're in configuration mode, it will show the
appropriate configuration screen.
*/

  if (displayMode == 1) {
    //we're displaying the currently selected antennas

    lcd.clear(); //Clear the display - this moves the cursor to home position as well
    
    if (radioSelected == 1) {
      lcd.print("1>>");
    } else {
      lcd.print("1: ");
    }
    lcd.print(coaxDescriptions[radio1]);
    lcd.setCursor(0, 1);    //move to second line

    if (radioSelected == 2) {
      lcd.print("2>>");
    } else {
      lcd.print("2: ");
    }
    lcd.print(coaxDescriptions[radio2]);

  }
  if (displayMode == 2) {
    //We're in the configuration mode - show the appropriate setting

    lcd.clear();
    switch (configScreen) {
    case 0:
      lcd.print("Firmware Version");
      lcd.setCursor(0, 1);    //move to second line
      lcd.print(FIRMWARE_VERSION);
      break;
    case 1:
      lcd.print("API Key");
      lcd.setCursor(0, 1);    //move to second line
      lcd.print(getAPIKey(false));
      break;
    case 2:
      lcd.print("Wifi SSID");
      lcd.setCursor(0, 1);    //move to second line
      lcd.print(WiFi.SSID());
      break;
    case 3:
      lcd.print("IP Mode");
      lcd.setCursor(0, 1);    //move to second line
      if (useStaticIP) {
        lcd.print("Static");
      } else {
        lcd.print("DHCP");
      }
      break;
    case 4:
      lcd.print("IP Address");
      lcd.setCursor(0, 1);    //move to second line
      lcd.print(WiFi.localIP().toString());
      break;
    case 5:
      lcd.print("IP Mask");
      lcd.setCursor(0, 1);    //move to second line
      lcd.print(WiFi.subnetMask().toString());
      break;
    case 6:
      lcd.print("Gateway");
      lcd.setCursor(0, 1);    //move to second line
      lcd.print(WiFi.gatewayIP().toString());
      break;
    }
  }

  
}
/******************************************************************************************/
void showSplash() {
/*
Show the branded Splash screen. This is saved to the display's EEPROM so it will be displayed 
at power on, and again during the boot process.
*/
  lcd.clear(); //Clear the display - this moves the cursor to home position as well
  lcd.print("    W0ZC.com    ");
  lcd.print("Coax Controller");


}
/******************************************************************************************/
void updateConfigScreen(int diff) {
/*
Updates the currently displayed configuration screen based on the twist from the multi-purpose knob. If the
knob is twisted, the screen will change.
*/ 
  //set the max limits for how far we can scroll
  if (diff > 3) diff = 3;
  if (diff < -3) diff = -3;

  configScreen += diff;
  if (configScreen > MAX_CONFIG_SCREENS) configScreen = configScreen - (MAX_CONFIG_SCREENS + 1);
  if (configScreen < 0) configScreen = configScreen + (MAX_CONFIG_SCREENS + 1);

  updateLCD();

}
/******************************************************************************************/
void updateAntenna(int radio, int diff) {
/*
Updates the antenna selection for the specified radio based on the twist from the multi-purpose knob. If 
the antenna is already selected, it will move to the next
*/
  //cap out the maximum clicks that can be made in a cycle
  if (diff > 3) diff=3;
  if (diff < -3) diff=-3;


  if (radio == 1) {
    radio1 = radio1 + diff;
    if (radio1 > 6) {
      radio1 = radio1 - 7;
    } else {
      if (radio1 < 0) {
        radio1 = radio1 + 6;
      }
    }

    //Check to see if Radio 2 already has this antenna selected (unless we're disconnecting)
    if (radio1 == radio2 && radio1 > 0) {
      if (diff > 0) {
        //clicking up
        radio1++;
        if (radio1 > 6) {
          radio1 = radio1 - 7;
        }
      } else {
        //clicking down
        radio1--;
        if (radio1 < 0) {
          radio1 = radio1 + 7;
        }
      }
    }

    connectAntenna(1, radio1, (diff > 0));
  } 

  if (radio == 2) {
    radio2 = radio2 + diff;
    if (radio2 > 6) {
      radio2 = radio2 - 7;
    } else {
      if (radio2 < 0) {
        radio2 = radio2 + 7;
      }
    }

    //Check to see if Radio 1 already has this antenna selected (unless we're disconnecting)
    if (radio1 == radio2 && radio2 > 0) {
      if (diff > 0) {
        //clicking up
        radio2++;
        if (radio2 > 6) {
          radio2 = radio2 - 7;
        }
      } else {
        //clicking down
        radio2--;
        if (radio2 < 0) {
          radio2 = radio2 + 7;
        }
      }
    }
    connectAntenna(2, radio2, (diff > 0));
  }
}
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

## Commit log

2024-04-08 Initial Project upload
    [Coax Switch Controller-B_Cu.gbr, Coax Switch Controller-B_Mask.gbr, Coax Switch Controller-B_Paste.gbr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]
2024-04-20 Updated to SerLCD library. Implemented customizable antenna port names.
2024-04-27 Finalized version 1.0.1 of firmware. Updated the lid STL.
    Lid now has a better fit and avoids the LCD circuit board inside the front panel.
    [Lid.FCStd, Lid.stl]
2024-08-29 Minor updates to PCB
2024-09-09 Updated to Kicad 8. Added bill of materials, and PCB's of the output.
    [Bill of Materials.csv, Coax Switch Controller.kicad_sch]
2026-09-16 Fixes for esp rebooting under high traffic
    [Firmware.ino]
2026-09-20 Notices about incompatible board releases
    [Firmware.ino]
